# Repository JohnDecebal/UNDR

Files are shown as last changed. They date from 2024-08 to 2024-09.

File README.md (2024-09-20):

# UNDR AUTO: Automatic WDT Tool for Espresso

## Description

UNDR AUTO is a fully automatic WDT (Weiss Distribution Technique) tool designed for espresso enthusiasts. This open-source DIY project combines 3D printed parts with electronic and mechanical components to create a precise and customizable coffee distribution tool. By evenly distributing coffee grounds in the portafilter basket, UNDR AUTO aims to improve the consistency and quality of espresso shots.

## Key Features

- Fully automatic operation with proximity sensor activation
- Adjustable portafilter basket depth
- Variable speed control for vertical movement and distribution
- Customizable distribution patterns with 24 needle slots
- Wi-Fi control via onboard ESP32-S3 webserver
- Compact design with custom UNDR PCB

## Components Overview

The UNDR AUTO utilizes a mix of off-the-shelf and custom components:

- NEMA 17 Stepper Motors for precise movement
- Lead Screw System for vertical adjustment
- Custom 3D printed parts for the main structure
- UNDR PCB with ESP32-S3 for control and connectivity
- Various fasteners and electronic components

For a detailed list, please refer to the Bill of Materials (BOM) in this repository.

## Current Status and Limitations

**Important:** UNDR AUTO is currently in a prototype stage. Potential builders should be aware of the following:

1. Some 3D printed parts may require minor adjustments for proper fit.
2. The current wiring setup is not optimal and requires careful handling.
3. Assembly can be challenging, with some hard-to-reach fastening points.
4. The portafilter mount is specifically designed for Cafe Racer machines and will need modification for other models.
5. There's significant room for improvement in various aspects of the design.

We welcome contributions to address these limitations and enhance the overall design.

## Assembly Guide

Follow these detailed steps to assemble your UNDR AUTO:

1. **3D Printing:**
   - Print all parts listed in the "3D Printed Parts" section of the BOM.
   - Ensure prints are clean and free of defects. Sand parts if necessary for proper fit.
   - Pay special attention to the tolerances of connecting parts.

2. **Prepare the Main Body:**
   - Assemble the four parts of the main body, ensuring they fit snugly together.
   - Install M4 heated inserts into designated holes on the main body. Use a soldering iron to carefully melt the inserts into place.
   - Install 2 heated inserts on the lead screw mount.
   - Apply a strong adhesive to glue the grounds shield holder in place on the body. Ensure proper alignment before the glue sets.

3. **Motor and Lead Screw Installation:**
   - Attach the NEMA 17 stepper motor to the motor mount using M3 screws. Ensure the motor is securely fastened.
   - Install the lead screw system, carefully aligning it with the motor shaft. Use a coupling to connect the motor shaft to the lead screw.

4. **Carriage and Portafilter Mount Assembly:**
   - Install 4 bearings (ID 4mm x OD 8mm x Width 3mm) onto the carriage.
   - Attach the lead screw nut to the carriage using two M3 tapping screws.
   - Connect the portafilter mount to the leadscrew carriage. Note: This connection should be secure but allow for some movement to accommodate different portafilter sizes.

5. **Electronics Installation:**
   - Place the UNDR PCB in the designated space at the bottom of the tool. 
   - Note: The current design doesn't include mounting points for the PCB. Handle with care when moving the assembled unit.
   - Connect the ESP32-S3 to the PCB, ensuring all pins are properly aligned.
   - Install the proximity sensor.

6. **Wiring:**
   - Connect stepper motors to the PCB using the provided cables. Double-check the connections to ensure proper motor direction.
   - Carefully route all wires to avoid interference with moving parts.
   - Use cable ties or electrical tape to secure wires neatly along the frame of the device.

7. **Distributor Assembly:**
   - Assemble the distributor, magnetic connector, lid, arm, and cog.
   - Ensure the distributor spins freely and is properly aligned with the portafilter position.

8. **Lid Assembly:**
   - Assemble the lid using its 4 parts.
   - If desired, install small neodymium magnets in the provided slots for a satisfying close. Ensure polarity is correct for proper attraction to the main body.

9. **Tray Preparation:**
   - Glue magnets in place on the tray and corresponding spots on the body. This allows the tray to snap in place and be easily removed for cleaning.

10. **Final Assembly:**
    - Attach the assembled lid to the main body. Verify that it opens and closes smoothly.
    - Install the bottom lid, securing it with the appropriate screws.
    - Attach the threaded grounds shield to its glued holder, ensuring it's properly aligned with the distributor.

11. **Software Installation:**
    - Connect the ESP32 to your computer using a USB cable.
    - Download the latest firmware from the GitHub repository.
    - Use the Arduino IDE or your preferred ESP32 flashing tool to upload the code to the ESP32.
    - Verify that the upload was successful by checking for any error messages in the IDE.

12. **Testing and Calibration:**
    - Power on the device and connect to its Wi-Fi network (default SSID: "UNDR AUTO").
    - Access the web interface by navigating to 192.168.1.100 in your web browser.
    - Use the interface to test all movements: vertical travel, distribution rotation, and sensor activation.
    - Adjust settings as needed for your specific setup and preferences.

**Important Assembly Tips:**
- Use 90-degree allen wrenches for hard-to-reach fasteners, particularly in the main body assembly.
- Take your time and don't force parts together. If something doesn't fit, double-check the 3D print quality and sand if necessary.
- If using a portafilter other than Cafe Racer, you'll need to modify the mount design. Measure your portafilter carefully and adjust the 3D model accordingly.
- When gluing parts (like magnets or the grounds shield holder), ensure proper alignment before the glue sets.
- When flashing the code, make sure you have the correct board and port selected in your IDE.
- If you encounter any issues during the flashing process, double-check your connections and try resetting the ESP32.

Remember, this is a prototype design and you may encounter challenges during assembly. Don't hesitate to reach out to the community for support or share your improvement ideas!

## Usage Instructions

1. Connect to the UNDR AUTO Wi-Fi network
2. Access the web interface at 192.168.1.100
3. Configure settings (basket depth, speeds, rotation)
4. Place the filled portafilter on the mount
5. The device will automatically start the distribution process
6. Remove the portafilter and tamp as usual

Note: The current version does not support profile saving or live monitoring.

## Customization and Contribution

We strongly encourage users to customize the UNDR AUTO and contribute to its development. Here are some ways you can get involved:

### Customization

1. **Portafilter Mount:**
   - The current design is specific to Cafe Racer machines. We encourage users with different machines to create and share alternative designs.
   - When designing a new mount:
     - Carefully measure your portafilter's dimensions and unique features.
     - Use CAD software to modify the existing design or create a new one.
     - Consider factors like weight distribution and stability.
     - Share your designs with the community to help others with similar machines.

2. **Distribution Patterns:**
   - Experiment with different needle configurations in the 24 available slots.
   - Share your findings on how different patterns affect extraction.

3. **Software Tweaks:**
   - Modify the Arduino code to add new features or optimize existing ones.
   - If you create useful modifications, consider submitting them as pull requests.

### Contributing to the Project

We welcome contributions in various areas:

1. **Hardware Improvements:**
   - Refine the 3D printed parts for better fit and easier assembly.
   - Design solutions for improved wire management.
   - Develop a more secure method for attaching the portafilter mount to the leadscrew carriage.
   - Create a mounting solution for the PCB to prevent movement during operation.

2. **Software Enhancements:**
   - Implement profile saving and loading functionality in the web interface.
   - Add live monitoring capabilities for real-time adjustment during operation.
   - Develop over-the-air (OTA) firmware update functionality.
   - Create a mobile app for easier control and monitoring.

3. **Testing and Quality Assurance:**
   - Develop standardized testing procedures for assembled units.
   - Create a quality checklist for 3D printed parts.
   - Report bugs or suggest improvements based on your experience with the device.

### How to Contribute

1. Fork the repository on GitHub.
2. Create a new branch for your feature or bug fix.
3. Make your changes, ensuring they adhere to the project's coding standards.
4. Test your changes thoroughly.
5. Submit a pull request with a clear description of your changes and their benefits.
6. Engage in any feedback or discussion about your contribution.

### Community Guidelines

- Be respectful and constructive in all interactions.
- When reporting issues, provide as much detail as possible, including steps to reproduce.
- For major changes or new features, open an issue for discussion before submitting a pull request.
- Follow the project's coding style and documentation standards.
- Ensure all contributions are your own work or properly attributed.

Your contributions, no matter how small, are valuable to the project and the entire UNDR AUTO community. Together, we can create an exceptional tool for espresso enthusiasts worldwide!

## License

Copyright 2024 Ionut Decebal, UNDR COFFEE

This project is licensed under the CERN Open Hardware Licence Version 2 - Strongly Reciprocal (CERN-OHL-S v2). You may redistribute and modify this project under the terms specified at https://ohwr.org/cern_ohl_s_v2.txt.

This project is distributed WITHOUT ANY EXPRESS OR IMPLIED WARRANTY, INCLUDING OF MERCHANTABILITY, SATISFACTORY QUALITY AND FITNESS FOR A PARTICULAR PURPOSE. Please see the CERN-OHL-S v2 for applicable conditions.

## Acknowledgments and Contact

- Inspired by WDT techniques discussed on r/espresso
- Thanks to all contributors and testers

For questions or support, contact:
John Decebal - undr.coffee@gmail.com

Project Repository: [https://github.com/JohnDecebal/UNDR](https://github.com/JohnDecebal/UNDR)

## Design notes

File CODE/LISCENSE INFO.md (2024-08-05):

The STL files in this directory are part of the UNDR AUTO project.
Copyright 2024 Ionut Decebal, UNDR COFFEE
Licensed under CERN-OHL-S v2 (https://ohwr.org/cern_ohl_s_v2.txt)
Source: https://github.com/JohnDecebal/UNDR

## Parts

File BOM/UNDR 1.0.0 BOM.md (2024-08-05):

# Bill of Materials: 3D Printed Project

## Electronic and Mechanical Components

| Item No. | Description | Quantity | Notes | Link |
|---|---|---|---|---|
| 1 | NEMA 17 Stepper Motor | 2 | | |
| 2 | Connection Cables for Stepper Motors | 2 | | |
| 3 | UNDR PCB | 1 | | |
| 4 | ESP32-S3 | 1 | Microcontroller for Wi-Fi connectivity and control | |
| 5 | M4 Heated Inserts | 6 | | |
| 6 | M4 Screws | 6 | 2x 25mm, 4x 12mm | |
| 7 | M2 Screws | 9 | 4x 10mm, 4x 12mm, 1x 20mm | |
| 8 | M3 Tapping Screws | 2 | | |
| 9 | Bearings | 4 | ID 4mm x OD 8mm x Width 3mm | |
| 10 | Lead Screw System | 1 | 8mm T8 with 100mm leadscrew Type 3 | [Amazon Link](https://www.amazon.co.uk/iYueshare-100mm-Printer-Trapezoidal-Coupling/dp/B09K7HXKJD/) |
| 11 | Proximity Sensor | 1 | Heschen M4 Inductive Proximity Sensor (Sheld Type, 10-30VDC 150mA PNP, Normally Closed NC, 3 Wire) | |

## 3D Printed Parts

| Item No. | Description | Quantity | Notes | Link |
|---|---|---|---|---|
| 12 | Main Body | 1 | Made out of 4 parts | |
| 13 | Lid | 1 | Made out of 4 parts | |
| 14 | Portafilter Mount | 1 | | |
| 15 | Leadscrew Carriage | 1 | | |
| 16 | Threaded Grounds Shield | 1 | | |
| 17 | Threaded Grounds Shield Holder | 1 | | |
| 18 | Motor Mount | 1 | | |
| 19 | Bottom Lid | 1 | | |
| 20 | Tray | 1 | | |
| 21 | Distributor | 1 | | |
| 22 | Distributor Magnetic Connector | 1 | | |
| 23 | Distributor Lid | 1 | | |
| 24 | Distributor Arm | 1 | | |
| 25 | Distributor Cog | 1 | | |

## Notes:
- Consider adding any required tools or consumables (e.g., filament for 3D printing)
- Verify that all necessary connecting parts (e.g., nuts, washers) are included
- Ensure you have enough filament for all 3D printed parts
- Use the 'Link' column to add URLs for purchasing components or downloading 3D model files

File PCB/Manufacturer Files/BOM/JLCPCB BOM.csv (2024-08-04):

Comment | Designator | Footprint | LCSC Part Number
10nF | C1 | Capacitor_SMD:C_0603_1608Metric | C100042
2.2uF | C2, C3 | Capacitor_SMD:C_0805_2012Metric | C19110
220uF | C4 | Capacitor_Tantalum_SMD:CP_EIA-7343-31_Kemet-D | C8024
22uF | C5 | Capacitor_SMD:C_1206_3216Metric | C12891
10uF | C6 | Capacitor_SMD:C_1206_3216Metric | C13585
100nF | C7 | Capacitor_SMD:C_1206_3216Metric | C24497
100uF | C8, C9 | Capacitor_SMD:CP_Elec_8x10 | C336212
B340A | D1 | Diode_SMD:D_SMA | C64982
SMAJ12CA-TR | D2 | Diode_SMD:D_SMA | C132951
Yellow | D3 | LED_SMD:LED_0603_1608Metric | C72038
DC-005-20A | J1 | Connector_BarrelJack:BarrelJack_Wuerth_6941xx301002 | C136744
Conn_01x03 | J2 | TerminalBlock_Phoenix:TerminalBlock_Phoenix_PT-1,5-3-3.5-H_1x03_P3.50mm_Horizontal | C557655
Conn_01x04 | J3, J5 | Connector_JST:JST_XH_B4B-XH-AM_1x04_P2.50mm_Vertical | C161871
Conn_02x03_Odd_Even | J4, J6 | Connector_PinHeader_2.54mm:PinHeader_2x03_P2.54mm_Vertical | C706893
Conn_01x22 | J7, J8 | Plugin,P=2.54mm | C7499337
Conn_01x08 | J9, J10, J11, J12 | Plugin,P=2.54mm | C2935979
22uH | L1 | SMD | C9905
HSU60P03 | Q1 | Package_TO_SOT_SMD:TO-252-2 | C845611
13k | R1 | Resistor_SMD:R_0603_1608Metric | C217729
4.12k | R2 | Resistor_SMD:R_0603_1608Metric | C861436
10k | R3, R6 | Resistor_SMD:R_0603_1608Metric | C25804
56k | R4 | Resistor_SMD:R_0603_1608Metric | C23206
18k | R5 | Resistor_SMD:R_0603_1608Metric | C25810
330R | R7 | Resistor_SMD:R_0603_1608Metric | C23138
TPS5430DDA | U1 | Package_SO:TI_SO-PowerPAD-8_ThermalVias | C9864

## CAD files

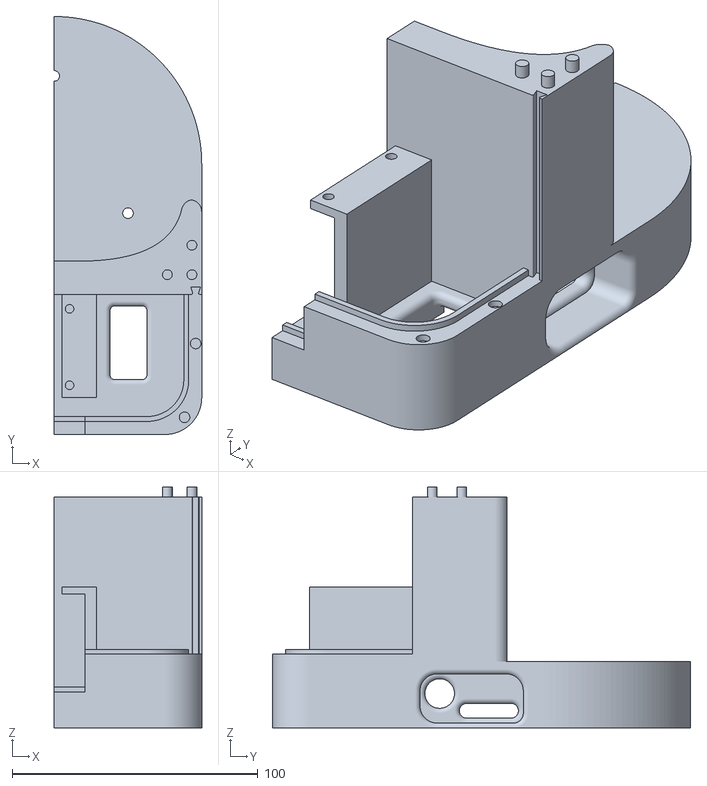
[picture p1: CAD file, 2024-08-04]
3D PRINTING/MAIN BODY/MAIN BODY - BODY LOWER LEFT.stl
60.0 x 170.0 x 98.0

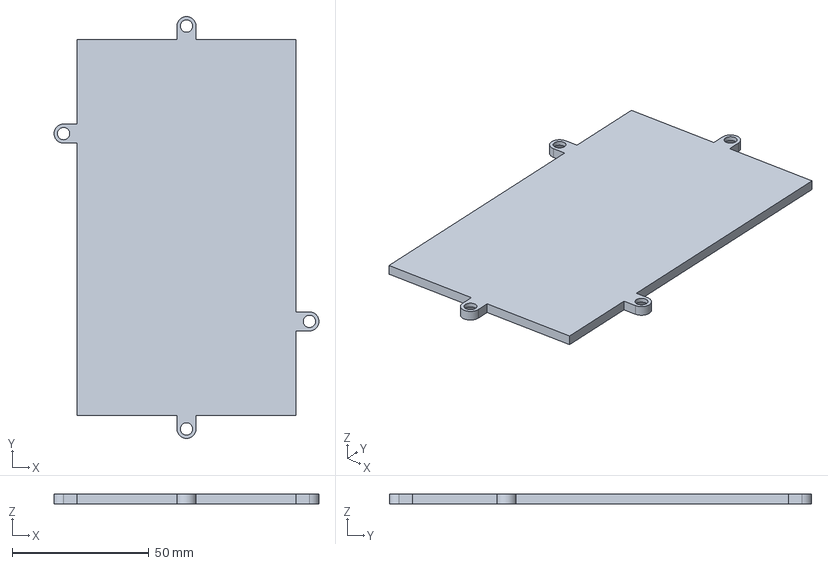
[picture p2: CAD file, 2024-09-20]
STEP/Assembly 1 - BOTTOM LID.step
97.0 x 154.5 x 3.50 mm

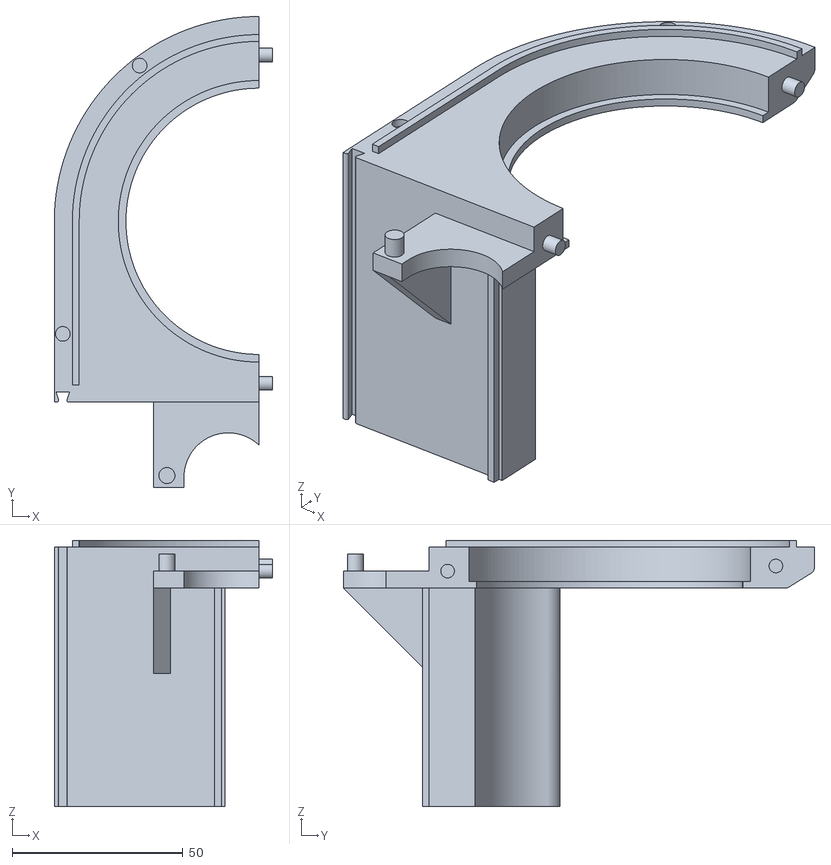
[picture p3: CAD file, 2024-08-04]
3D PRINTING/MAIN BODY/MAIN BODY - BODY UPPER RIGHT.stl
64.0 x 138.0 x 78.0

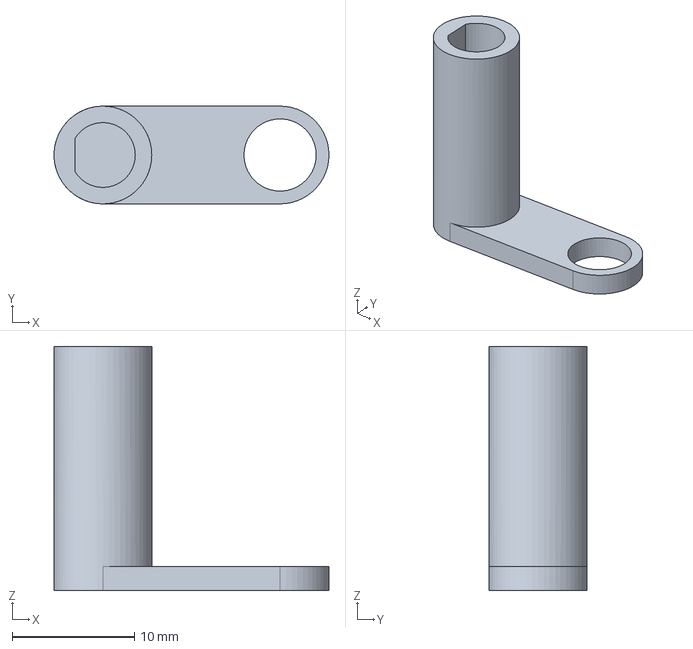
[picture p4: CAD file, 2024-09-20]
STEP/Assembly 1 - DISTRIBUTOR ARM.step
22.5 x 8.00 x 20.0 mm

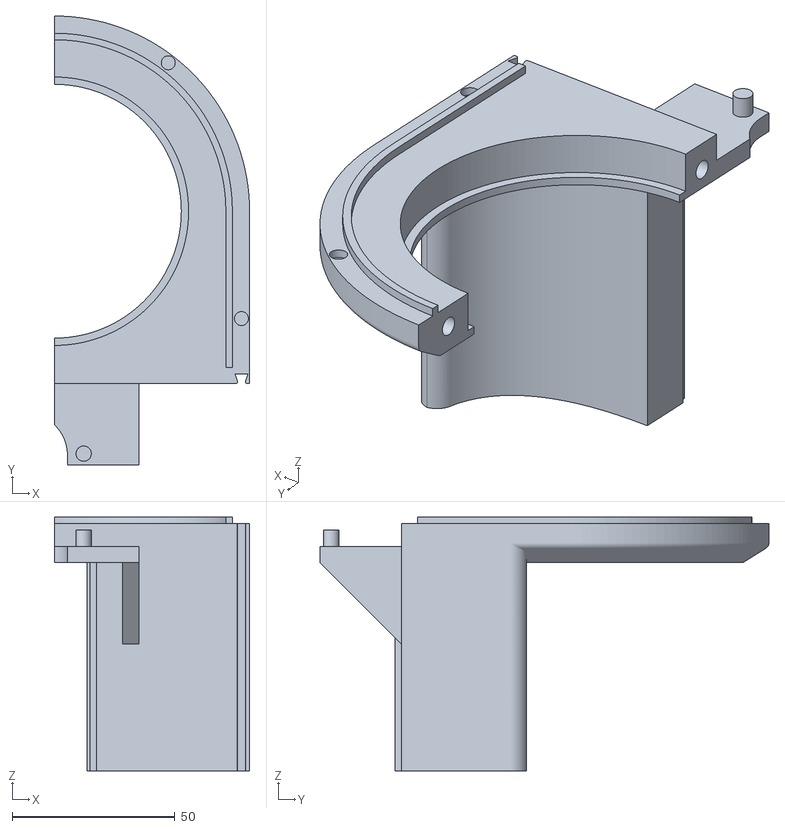
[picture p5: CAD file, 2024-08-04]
3D PRINTING/MAIN BODY/MAIN BODY - BODY UPPER LEFT.stl
60.0 x 138.0 x 78.0

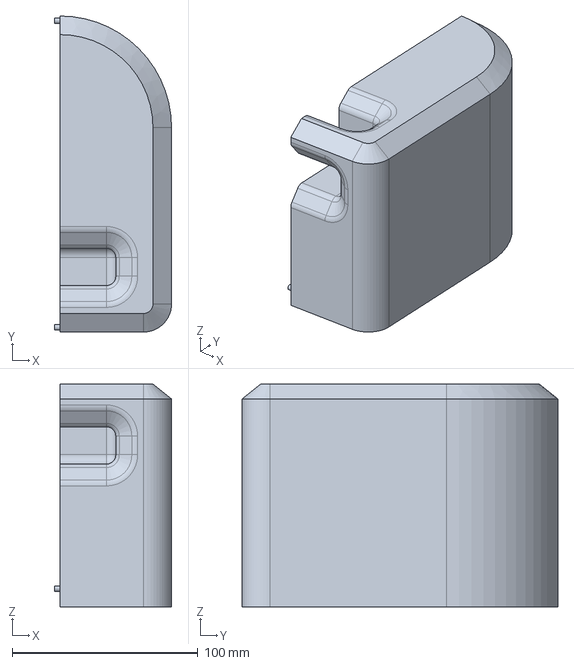
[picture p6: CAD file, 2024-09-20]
STEP/Assembly 1 - LID UP LEFT.step
63.0 x 170.0 x 119.8 mm

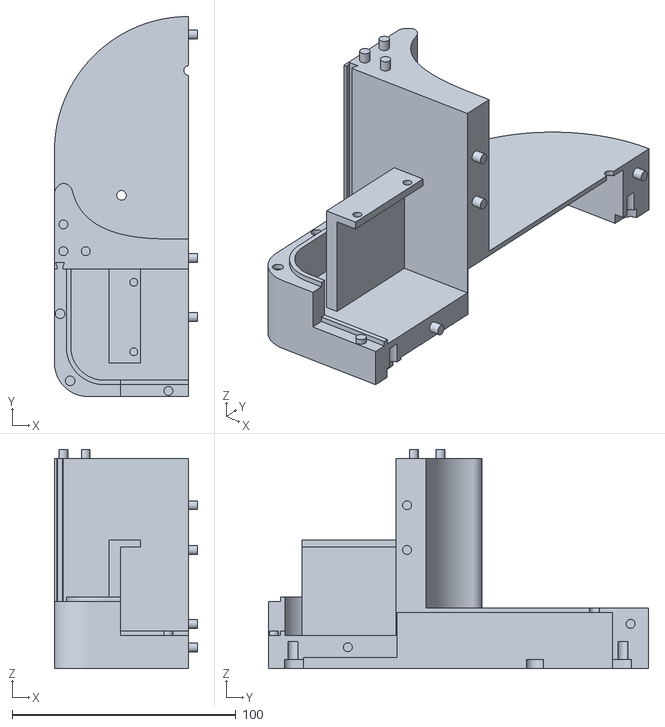
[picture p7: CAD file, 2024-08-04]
3D PRINTING/MAIN BODY/MAIN BODY - BODY LOWER RIGHT.stl
64.0 x 170.0 x 98.0

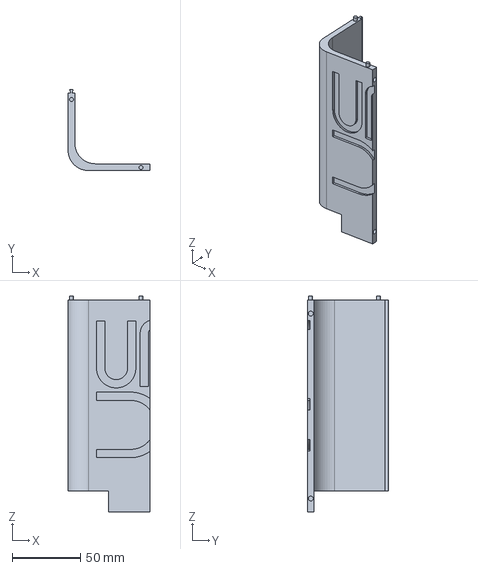
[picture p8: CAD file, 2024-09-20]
STEP/Assembly 1 - LID LOW RIGHT.step
60.0 x 59.4 x 158.0 mm

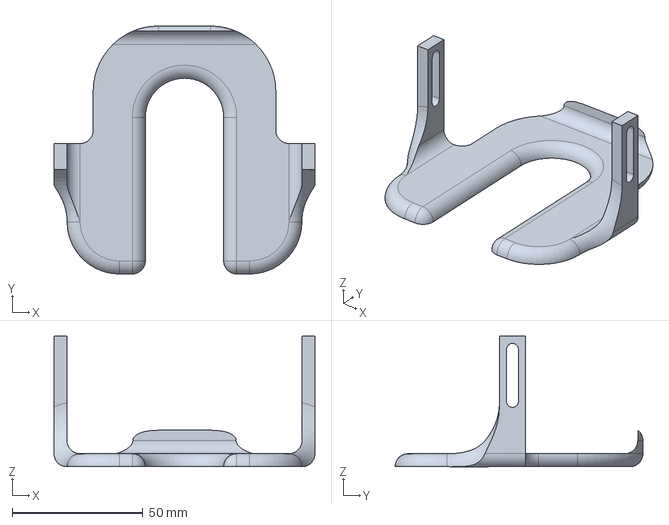
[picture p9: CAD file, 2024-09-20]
STEP/Assembly 1 - PORTAFILTER MOUNT BOTTOM.step
100.0 x 95.0 x 50.0 mm

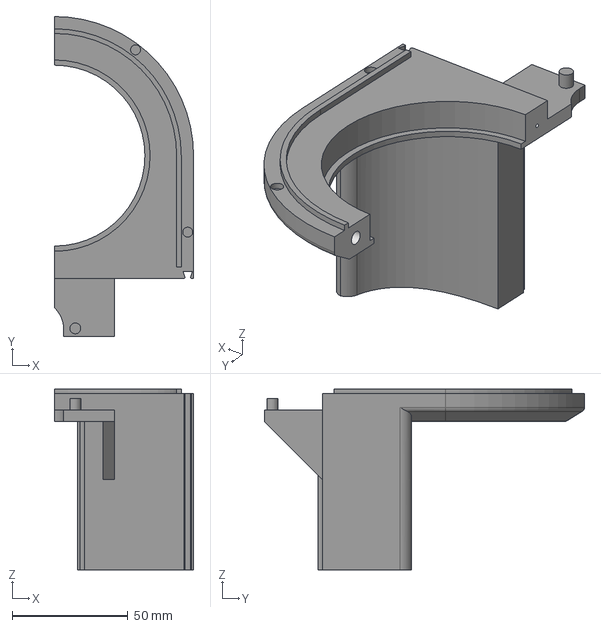
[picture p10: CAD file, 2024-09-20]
STEP/Assembly 1 - BODY UPPER LEFT.step
60.0 x 138.0 x 78.0 mm

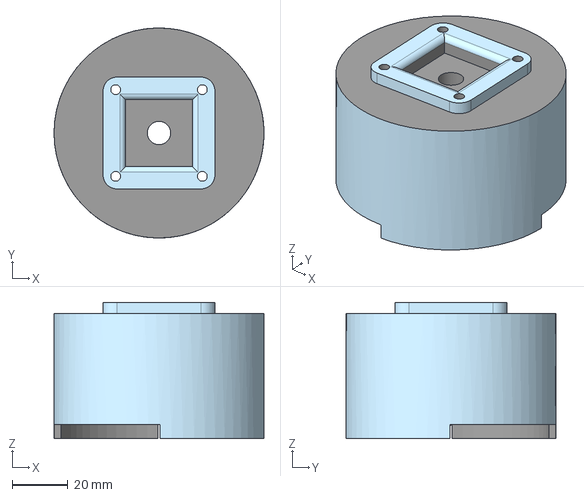
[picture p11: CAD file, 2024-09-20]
STEP/Assembly 1 - MOTOR MOUNT.step
75.1 x 75.1 x 48.7 mm

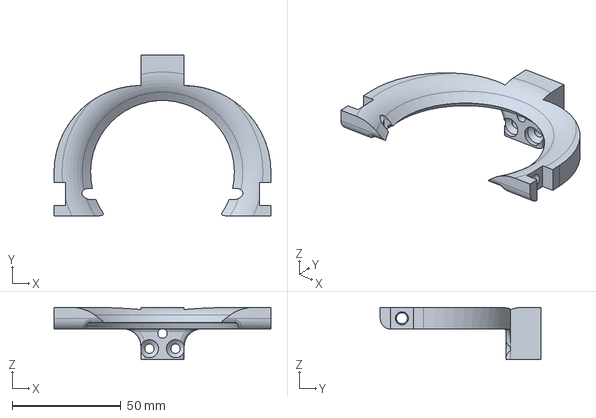
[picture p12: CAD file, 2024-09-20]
STEP/Assembly 1 - PORTAFILTER MOUNT TOP.step
100.0 x 74.0 x 24.0 mm

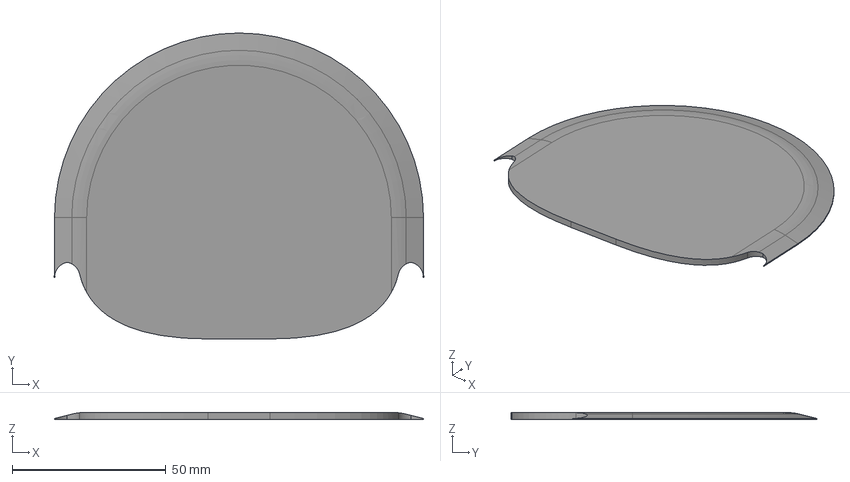
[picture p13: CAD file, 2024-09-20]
STEP/Assembly 1 - TRAY.step
120.0 x 99.5 x 2.40 mm

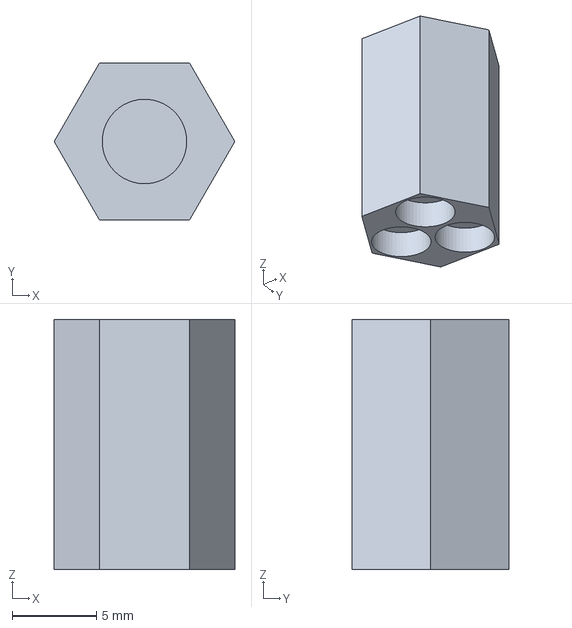
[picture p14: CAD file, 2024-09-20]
STEP/Assembly 1 - INNER DISTRIBUTOR MAG.step
10.7 x 9.27 x 14.8 mm

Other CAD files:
STEP/Assembly 1 - BODY UPPER RIGHT.step
STEP/Assembly 1 - INNER BARREL.step
STEP/Assembly 1 - OUTTER BARREL.step
STEP/Assembly 1 - DISTRIBUTOR COG.step
3D PRINTING/BOTTOM LID.stl
3D PRINTING/DRIVE SYSTEM/DISTRIBUTOR SYSTEM - DISTRIBUTOR COG.stl
3D PRINTING/DRIVE SYSTEM/DRIVE SYSTEM - DISTRIBUTOR MAGNET CONNECTOR.stl
3D PRINTING/DRIVE SYSTEM/DRIVE SYSTEM - DISTRIBUTOR ARM.stl
3D PRINTING/DRIVE SYSTEM/DRIVE SYSTEM - DISTRIBUTOR LID.stl
3D PRINTING/DRIVE SYSTEM/DRIVE SYSTEM - DISTRIBUTOR.stl
3D PRINTING/GROUND SHIELD.stl
3D PRINTING/GROUNDS SHIED HOLDER.stl
3D PRINTING/LEADSCREW CARRIAGE.stl
3D PRINTING/LID/LID - LID LOW LEFT.stl
3D PRINTING/LID/LID - LID LOW RIGHT.stl
3D PRINTING/LID/LID - LID UP LEFT.stl
3D PRINTING/LID/LID - LID UP RIGHT.stl
3D PRINTING/PORTAFILTER MOUNT.stl
3D PRINTING/TRAY.stl
STEP/Assembly 1 - BODY LOWER LEFT.step
STEP/Assembly 1 - BODY LOWER RIGHT.step
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

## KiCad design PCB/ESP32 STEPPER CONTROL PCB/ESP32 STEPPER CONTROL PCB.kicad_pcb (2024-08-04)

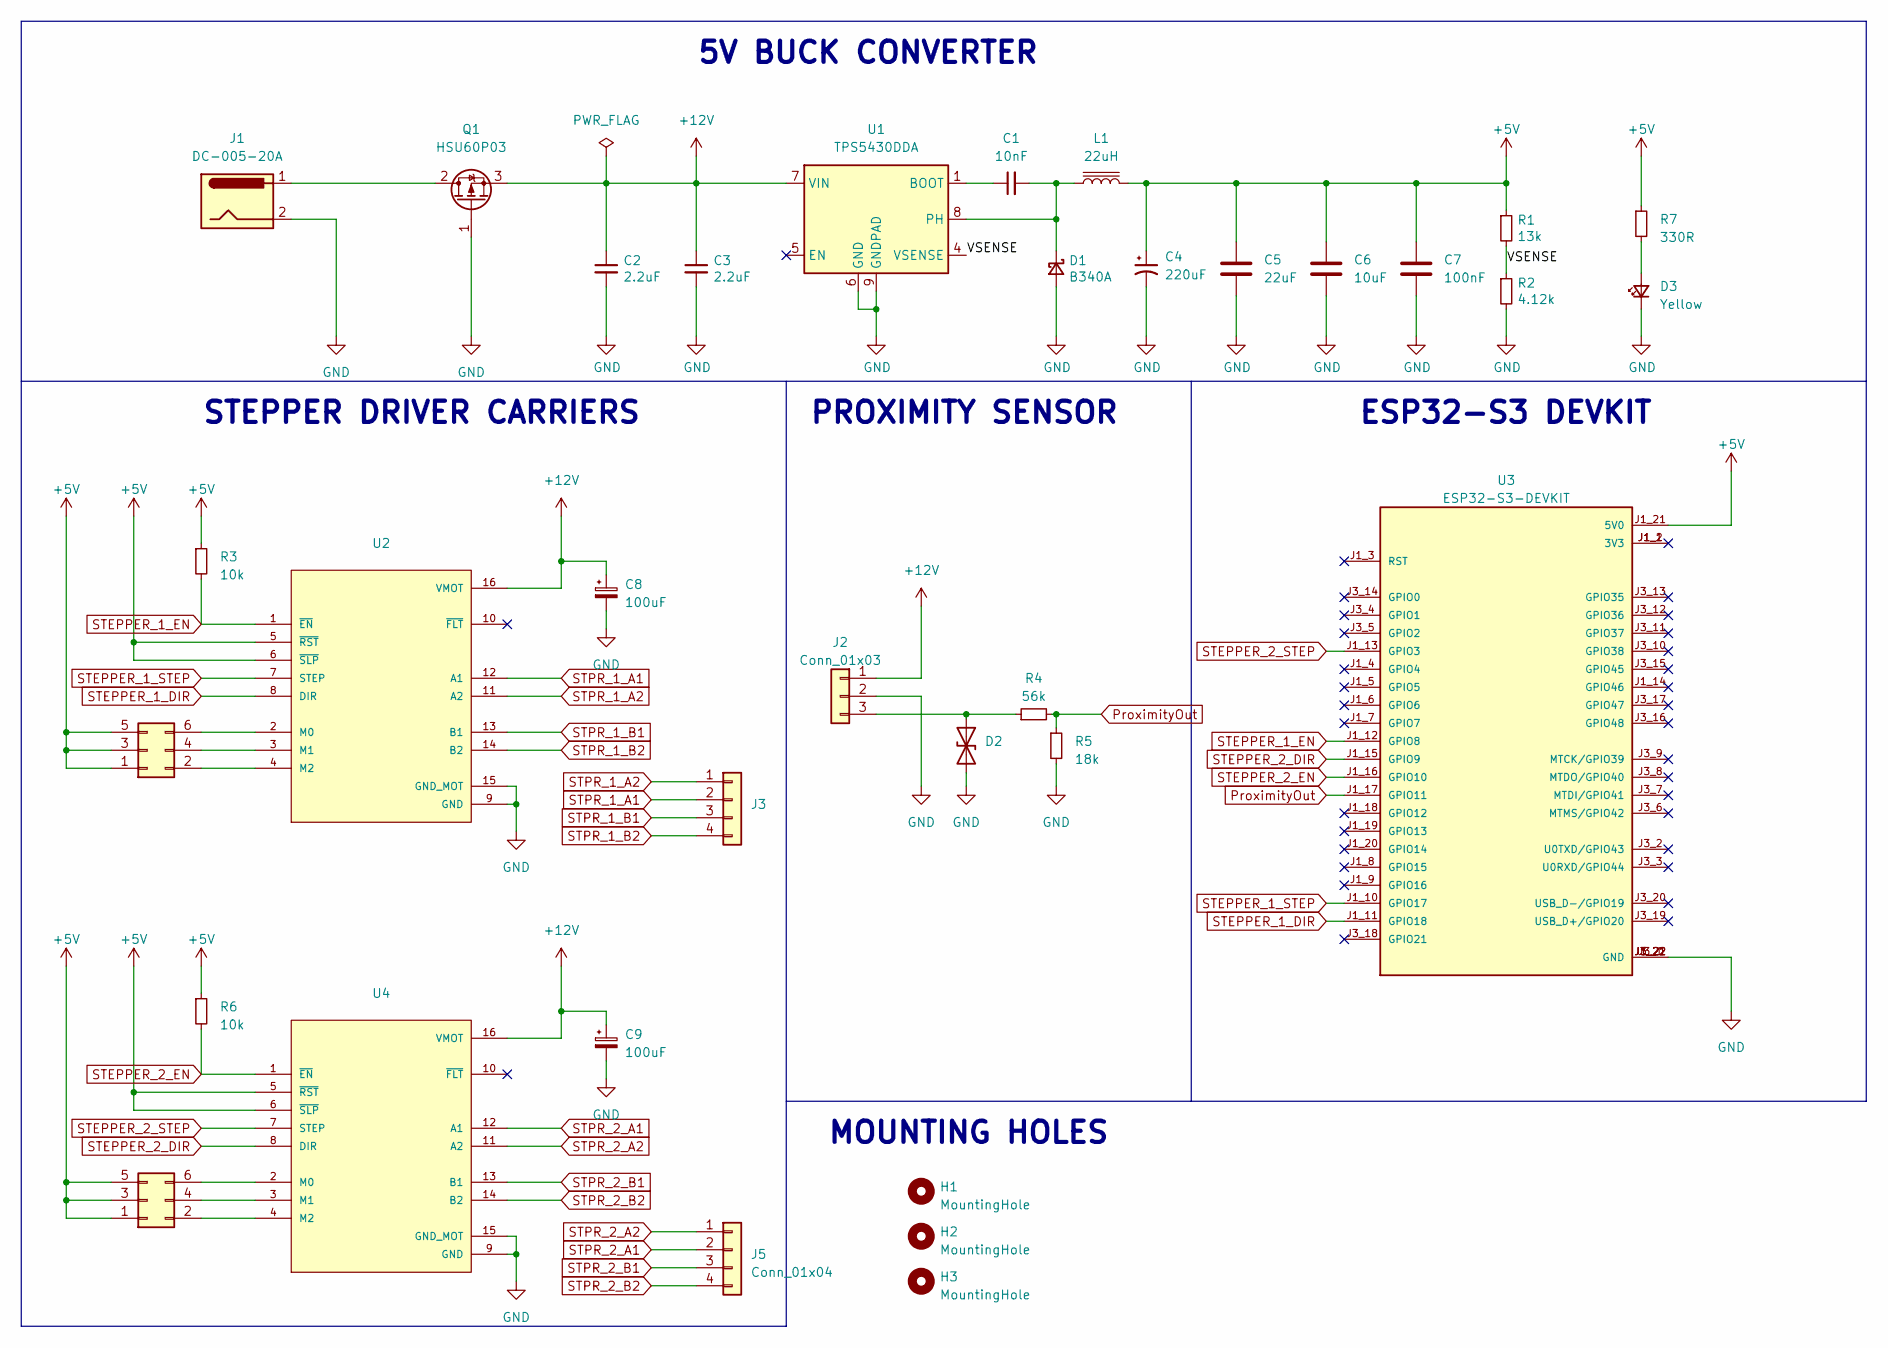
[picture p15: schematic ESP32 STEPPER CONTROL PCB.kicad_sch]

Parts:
C1: 10nF; C_0603_1608Metric; LCSC Part # C100042
C2, C3: 2.2uF; C_0805_2012Metric; LCSC Part # C19110
C4: 220uF; CP_EIA-7343-31_Kemet-D; LCSC Part # C8024
C5: 22uF; C_1206_3216Metric; LCSC Part # C12891
C6: 10uF; C_1206_3216Metric; LCSC Part # C13585
C7: 100nF; C_1206_3216Metric; LCSC Part # C24497
C8, C9: 100uF; CP_Elec_8x10; LCSC Part # C336212
D1: B340A; D_SMA; LCSC Part # C64982
D2: SMAJ12CA-TR; D_SMA; LCSC Part # C132951
D3: Yellow; LED_0603_1608Metric; LCSC Part # C72038
H1, H2, H3: MountingHole; MountingHole_3.2mm_M3_DIN965
J1: DC-005-20A; BarrelJack_Wuerth_6941xx301002; LCSC Part # C136744
J2: Conn_01x03; TerminalBlock_Phoenix_PT-1,5-3-3.5-H_1x03_P3.50mm_Horizontal; LCSC Part # C557655
J3, J5: Conn_01x04; JST_XH_B4B-XH-AM_1x04_P2.50mm_Vertical; LCSC Part # C161871
J4, J6: Conn_02x03_Odd_Even; PinHeader_2x03_P2.54mm_Vertical; LCSC Part # C706893
L1: 22uH; SMDRI127-220MT; LCSC Part # C9905
Q1: HSU60P03; TO-252-2; LCSC Part # C845611
R1: 13k; R_0603_1608Metric; LCSC Part # C217729
R2: 4.12k; R_0603_1608Metric; LCSC Part # C861436
R3, R6: 10k; R_0603_1608Metric; LCSC Part # C25804
R4: 56k; R_0603_1608Metric; LCSC Part # C23206
R5: 18k; R_0603_1608Metric; LCSC Part # C25810
R7: 330R; R_0603_1608Metric; LCSC Part # C23138
U1: TPS5430DDA; TI_SO-PowerPAD-8_ThermalVias; LCSC Part # C9864
U2, U4: DRV8825_STEPPER_MOTOR_DRIVER_CARRIER
U3: ESP32-S3-DEVKIT; ESP32-S3-DEVKITC

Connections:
+5V: C4.1, C5.1, C6.1, C7.1, J4.1, J4.3, J4.5, J6.1, J6.3, J6.5, L1.2, R1.1, R3.1, R6.1, R7.1, U2.5 (~RST), U2.6 (~SLP), U3.J1_21 (5V0), U4.5 (~RST), U4.6 (~SLP)
+12V: C2.1, C3.1, C8.1, C9.1, J2.1, Q1.3 (S), U1.7 (VIN), U2.16 (VMOT), U4.16 (VMOT)
/VSENSE: R1.2, R2.1, U1.4 (VSENSE)
GND: C2.2, C3.2, C4.2, C5.2, C6.2, C7.2, C8.2, C9.2, D1.2 (A), D2.2 (A2), D3.1 (K), J1.2, J2.2, Q1.1 (G), R2.2, R5.2, U1.6 (GND), U1.9 (GNDPAD), U2.9 (GND), U2.15 (GND_MOT), U3.J1_22 (GND), U3.J3_1 (GND), U3.J3_21 (GND), U3.J3_22 (GND), U4.9 (GND), U4.15 (GND_MOT)
unnamed: C1.2, D1.1 (K), L1.1, U1.8 (PH)
unnamed: D2.1 (A1), J2.3, R4.1
unnamed: D3.2 (A), R7.2
unnamed: J4.2, U2.4 (M2)
unnamed: J4.4, U2.3 (M1)
unnamed: J4.6, U2.2 (M0)
unnamed: J6.2, U4.4 (M2)
unnamed: J6.4, U4.3 (M1)
unnamed: J6.6, U4.2 (M0)
unnamed: J1.1, Q1.2 (D)
unnamed: C1.1, U1.1 (BOOT)
ProximityOut: R4.2, R5.1, U3.J1_17 (GPIO11)
STEPPER_1_DIR: U2.8 (DIR), U3.J1_11 (GPIO18)
STEPPER_1_EN: R3.2, U2.1 (~EN), U3.J1_12 (GPIO8)
STEPPER_1_STEP: U2.7 (STEP), U3.J1_10 (GPIO17)
STEPPER_2_DIR: U3.J1_15 (GPIO9), U4.8 (DIR)
STEPPER_2_EN: R6.2, U3.J1_16 (GPIO10), U4.1 (~EN)
STEPPER_2_STEP: U3.J1_13 (GPIO3), U4.7 (STEP)
STPR_1_A1: J3.2, U2.12 (A1)
STPR_1_A2: J3.1, U2.11 (A2)
STPR_1_B1: J3.3, U2.13 (B1)
STPR_1_B2: J3.4, U2.14 (B2)
STPR_2_A1: J5.2, U4.12 (A1)
STPR_2_A2: J5.1, U4.11 (A2)
STPR_2_B1: J5.3, U4.13 (B1)
STPR_2_B2: J5.4, U4.14 (B2)

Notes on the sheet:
STEPPER DRIVER CARRIERS
PROXIMITY SENSOR
ESP32-S3 DEVKIT
5V BUCK CONVERTER
MOUNTING HOLES

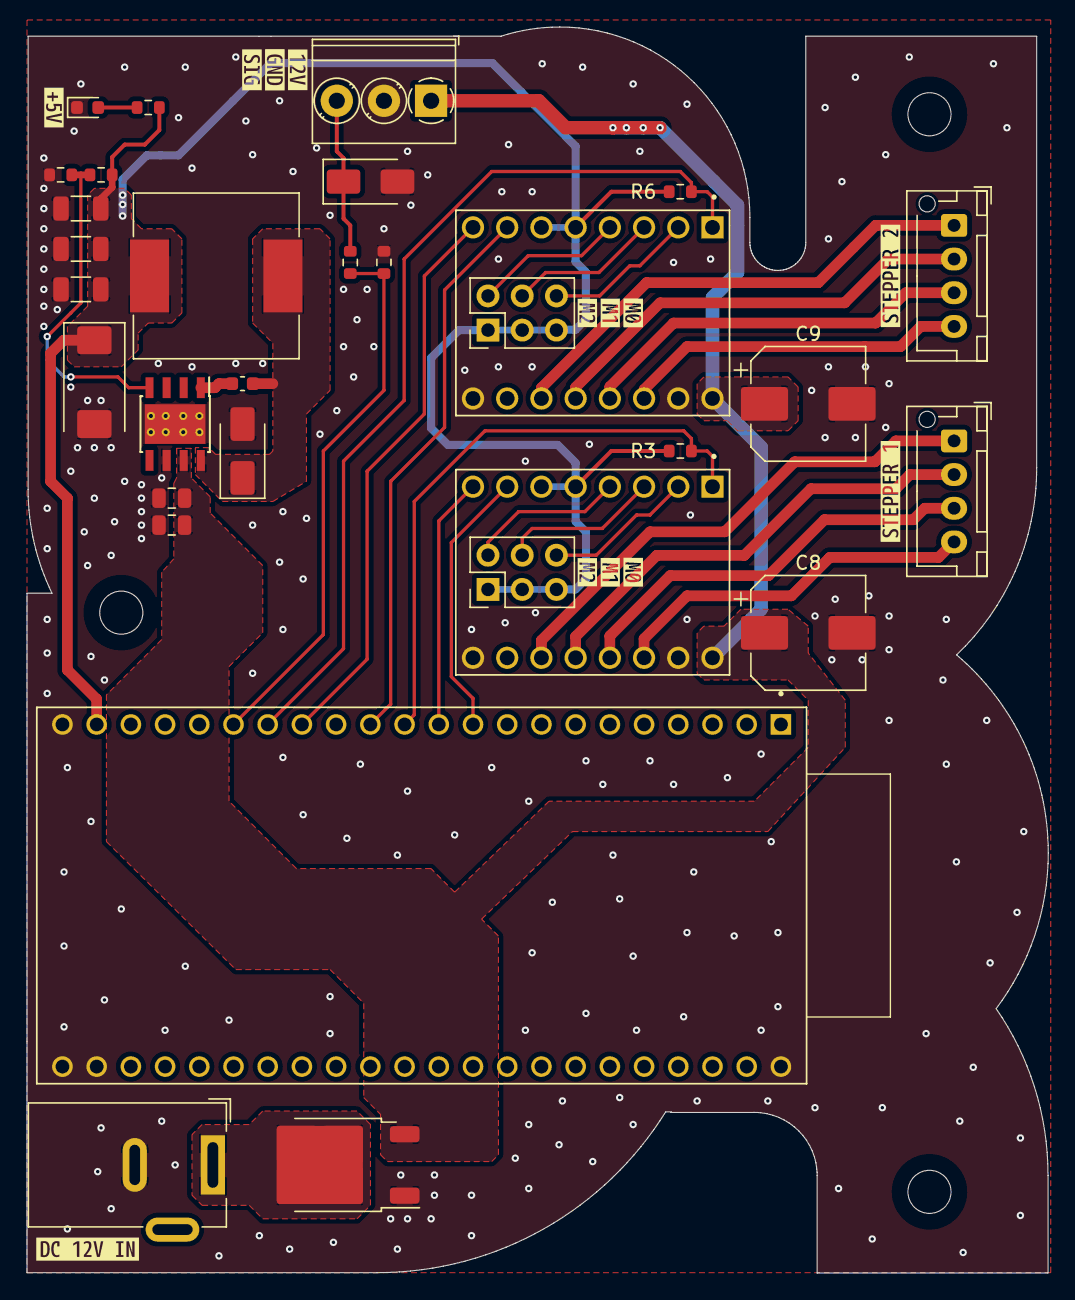
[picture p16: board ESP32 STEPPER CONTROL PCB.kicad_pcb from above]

Board: 2 copper layers, 75.8 x 92.5 mm, 47 parts (0 on the bottom side), 30 nets.

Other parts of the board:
kibuzzard-661D4DC0: G***; kibuzzard-661D4DC0
kibuzzard-661D7A6E: G***; kibuzzard-661D7A6E
kibuzzard-661D7A47: G***; kibuzzard-661D7A47
kibuzzard-661D7A91, kibuzzard-661D7A91#2: G***; kibuzzard-661D7A91
kibuzzard-661D7AAA, kibuzzard-661D7AAA#2: G***; kibuzzard-661D7AAA
kibuzzard-661D7AB9, kibuzzard-661D7AB9#2: G***; kibuzzard-661D7AB9
kibuzzard-661D7B73: G***; kibuzzard-661D7B73
kibuzzard-661D7B98: G***; kibuzzard-661D7B98
kibuzzard-661D7BA7: G***; kibuzzard-661D7BA7
kibuzzard-661D68F2: G***; kibuzzard-661D68F2

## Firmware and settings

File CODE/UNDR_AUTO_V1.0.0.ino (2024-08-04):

#include <WiFi.h>
#include <WebServer.h>
#include <AccelStepper.h>
#include <EEPROM.h>

const char* ssid = "UNDR AUTO";
const char* password = "undrauto";

WebServer server(80);

// Pin assignments
const int STEPPER1_PUL_PIN = 17;
const int STEPPER1_DIR_PIN = 18;
const int STEPPER2_PUL_PIN = 3;
const int STEPPER2_DIR_PIN = 9;
const int ENABLE_PIN_1 = 8;
const int ENABLE_PIN_2 = 10;
const int BUTTON_PIN = 11;

AccelStepper stepper1(1, STEPPER1_PUL_PIN, STEPPER1_DIR_PIN);
AccelStepper stepper2(1, STEPPER2_PUL_PIN, STEPPER2_DIR_PIN);

// Variables
int lastButtonState = 0;
int maxSpeed1; // Variable to store the maximum speed for stepper1
int maxSpeed2; // Variable to store the maximum speed for stepper2

// EEPROM addresses
const int ADDR_RPM = 0;
const int ADDR_REVS = 2;
const int ADDR_BASKET_DEPTH = 4;
const int ADDR_SPEED = 6;
const int ADDR_DIRECTION = 8;

// History
const int MAX_HISTORY = 25;

struct HistoryItem {
  unsigned long id;
  int rpm;
  int revs;
  int depth;
  int speed;
  int direction;
};

HistoryItem history[MAX_HISTORY];
int historyCount = 0;

// EEPROM functions
void EEPROMWriteInt(int address, int value) {
  byte low = value & 0xFF;
  byte high = (value >> 8) & 0xFF;
  EEPROM.write(address, low);
  EEPROM.write(address + 1, high);
  EEPROM.commit();
}

int EEPROMReadInt(int address) {
  byte low = EEPROM.read(address);
  byte high = EEPROM.read(address + 1);
  return (high << 8) | low;
}

// Motor control functions
void liftPortafilter(int basketDepthValue, int speedValue) {
  maxSpeed1 = speedValue * (800 / 60); // Assuming 800 steps per revolution
  stepper1.setCurrentPosition(0);
  stepper1.setMaxSpeed(maxSpeed1);
  stepper1.setAcceleration(800 * (speedValue / 60));
  stepper1.runToNewPosition(40*basketDepthValue);
}

void spinDistributor(int rpmValue, int revsValue, int directionValue) {
  maxSpeed2 = rpmValue * (3200 / 60); // Assuming 3200 steps per revolution
  stepper2.setCurrentPosition(0);
  stepper2.setMaxSpeed(maxSpeed2);
  stepper2.setAcceleration(3200 * (rpmValue / 60));
  int targetPosition = directionValue == 0 ? 3200 * revsValue : -3200 * revsValue;
  stepper2.runToNewPosition(targetPosition);
}

void lowerPortafilter() {
  stepper1.runToNewPosition(0);
}

String css() {
  String styles = "<style>";
  styles += "body { background-color: #000; color: #fff; font-family: 'Inter', sans-serif; margin: 0; padding: 0; min-height: 100vh; display: flex; flex-direction: column; }";
  styles += ".container { max-width: 800px; margin: 0 auto; padding: 20px; flex-grow: 1; display: flex; flex-direction: column; justify-content: center; }";
  styles += "h1 { text-align: center; margin-top: 0; }";
  styles += "form { margin-top: 30px; }";
  styles += "label { display: block; margin-bottom: 10px; }";
  styles += "input[type='number'], select { width: 100%; padding: 8px; background-color: #fff; color: #000; border: none; border-radius: 4px; box-sizing: border-box; }";
  styles += "input[type='submit'], input[type='button'] { display: block; width: 100%; padding: 10px; margin-top: 20px; background-color: #fff; color: #000; border: none; border-radius: 4px; cursor: pointer; }";
  styles += "table { width: 100%; border-collapse: collapse; }";
  styles += "th, td { padding: 8px; text-align: left; border-bottom: 1px solid #fff; }";
  styles += "@media screen and (max-width: 600px) {";
  styles += "input[type='number'], select { padding: 12px; }";
  styles += "input[type='submit'], input[type='button'] { padding: 12px; }";
  styles += "}";
  styles += "</style>";
  return styles;
}

void handleRoot() {
  String html = "<!DOCTYPE html><html><head>";
  html += "<title>UNDR AUTO</title>";
  html += "<meta name='viewport' content='width=device-width, initial-scale=1'>";
  html += "<link href='https://fonts.googleapis.com/css2?family=Inter:wght@400;700&display=swap' rel='stylesheet'>";
  html += css();
  html += "</head><body>";
  html += "<div class='container'>";
  html += "<h1>UNDR AUTO</h1>";
  html += "<form method='POST' action='/update'>";
  html += "<label for='rpm'>RPM:</label>";
  html += "<input type='number' id='rpm' name='rpm' value='" + String(EEPROMReadInt(ADDR_RPM)) + "' required>";
  html += "<label for='revs'>Revolutions:</label>";
  html += "<input type='number' id='revs' name='revs' value='" + String(EEPROMReadInt(ADDR_REVS)) + "' required>";
  html += "<label for='depth'>Basket Depth:</label>";
  html += "<input type='number' id='depth' name='depth' value='" + String(EEPROMReadInt(ADDR_BASKET_DEPTH)) + "' required>";
  html += "<label for='speed'>Speed:</label>";
  html += "<input type='number' id='speed' name='speed' value='" + String(EEPROMReadInt(ADDR_SPEED)) + "' required>";
  html += "<label for='direction'>Rotation Direction:</label>";
  html += "<select id='direction' name='direction'>";
  html += "<option value='0'";
  html += (EEPROMReadInt(ADDR_DIRECTION) == 0 ? " selected" : "");
  html += ">Clockwise</option>";
  html += "<option value='1'";
  html += (EEPROMReadInt(ADDR_DIRECTION) == 1 ? " selected" : "");
  html += ">Counterclockwise</option>";
  html += "</select>";
  html += "<input type='submit' value='Update'>";
  html += "</form>";
  html += "<form method='POST' action='/start'>";
  html += "<input type='submit' value='Start Distribution'>";
  html += "</form>";
  html += "<form method='GET' action='/manual'>";
  html += "<input type='submit' value='Manual Settings'>";
  html += "</form>";
  html += "<form method='GET' action='/history'>";
  html += "<input type='submit' value='View History'>";
  html += "</form>";
  html += "<form method='GET' action='/simulation'>";
  html += "<input type='submit' value='Simulation'>";
  html += "</form>";
  html += "</div>";
  html += "</body></html>";
  server.send(200, "text/html", html);
}

void handleUpdate() {
  if (server.hasArg("rpm")) {
    int rpmValue = server.arg("rpm").toInt();
    EEPROMWriteInt(ADDR_RPM, rpmValue);
  }
  if (server.hasArg("revs")) {
    int revsValue = server.arg("revs").toInt();
    EEPROMWriteInt(ADDR_REVS, revsValue);
  }
  if (server.hasArg("depth")) {
    int depthValue = server.arg("depth").toInt();
    EEPROMWriteInt(ADDR_BASKET_DEPTH, depthValue);
  }
  if (server.hasArg("speed")) {
    int speedValue = server.arg("speed").toInt();
    EEPROMWriteInt(ADDR_SPEED, speedValue);
  }
  if (server.hasArg("direction")) {
    int directionValue = server.arg("direction").toInt();
    EEPROMWriteInt(ADDR_DIRECTION, directionValue);
  }
  server.sendHeader("Location", "/");
  server.send(302);
}

void handleStart() {
  int rpmValue = EEPROMReadInt(ADDR_RPM);
  int revsValue = EEPROMReadInt(ADDR_REVS);
  int basketDepthValue = EEPROMReadInt(ADDR_BASKET_DEPTH);
  int speedValue = EEPROMReadInt(ADDR_SPEED);
  int directionValue = EEPROMReadInt(ADDR_DIRECTION);

  // Activate motors
  digitalWrite(ENABLE_PIN_1, LOW);
  digitalWrite(ENABLE_PIN_2, LOW);

  // Wait 0.5 seconds
  delay(500);

  // Lift portafilter
  liftPortafilter(basketDepthValue, speedValue);

  // Spin distributor
  spinDistributor(rpmValue, revsValue, directionValue);

  // Lower portafilter
  lowerPortafilter();

  // Deactivate motors
  digitalWrite(ENABLE_PIN_1, HIGH);
  digitalWrite(ENABLE_PIN_2, HIGH);

  // Add a new history item
  addHistoryItem(rpmValue, revsValue, basketDepthValue, speedValue, directionValue);

  server.sendHeader("Location", "/");
  server.send(302);
}

void handleManual() {
  String html = "<!DOCTYPE html><html><head>";
  html += "<title>UNDR AUTO - Manual Settings</title>";
  html += "<meta name='viewport' content='width=device-width, initial-scale=1'>";
  html += "<link href='https://fonts.googleapis.com/css2?family=Inter:wght@400;700&display=swap' rel='stylesheet'>";
  html += css();
  html += "</head><body>";
  html += "<div class='container'>";
  html += "<h1>Manual Settings</h1>";
  html += "<form method='POST' action='/stepper1'>";
  html += "<input type='submit' name='direction' value='Up'>";
  html += "<input type='submit' name='direction' value='Down'>";
  html += "</form>";
  html += "<form method='POST' action='/stepper2'>";
  html += "<input type='submit' name='direction' value='Clockwise'>";
  html += "<input type='submit' name='direction' value='Counter Clockwise'>";
  html += "</form>";
  html += "<form method='GET' action='/'>";
  html += "<input type='submit' value='Back'>";
  html += "</form>";
  html += "</div>";
  html += "</body></html>";
  server.send(200, "text/html", html);
}

void handleStepper1() {
  if (server.hasArg("direction")) {
    String direction = server.arg("direction");
    
    // Activate motor 1
    digitalWrite(ENABLE_PIN_1, LOW);
    
    if (direction == "Up") {
      int speedValue = EEPROMReadInt(ADDR_SPEED);
      maxSpeed1 = speedValue * (800 / 60);
      stepper1.setCurrentPosition(0);
      stepper1.setMaxSpeed(maxSpeed1);
      stepper1.setAcceleration(800 * (speedValue / 60));
      stepper1.runToNewPosition(100); // Move stepper 1 up by 100 steps
    } else if (direction == "Down") {
      int speedValue = EEPROMReadInt(ADDR_SPEED);
      maxSpeed1 = speedValue * (800 / 60);
      stepper1.setCurrentPosition(0);
      stepper1.setMaxSpeed(maxSpeed1);
      stepper1.setAcceleration(800 * (speedValue / 60));
      stepper1.runToNewPosition(-100); // Move stepper 1 down by 100 steps
    }
    
    // Deactivate motor 1
    digitalWrite(ENABLE_PIN_1, HIGH);
  }
  server.sendHeader("Location", "/manual");
  server.send(302);
}

void handleStepper2() {
  if (server.hasArg("direction")) {
    String direction = server.arg("direction");
    
    // Activate motor 2
    digitalWrite(ENABLE_PIN_2, LOW);
    
    if (direction == "Clockwise") {
      stepper2.setCurrentPosition(0);
      stepper2.setAcceleration(3200);
      stepper2.runToNewPosition(100); // Spin stepper 2 clockwise by 100 steps
    } else if (direction == "Counter Clockwise") {
      stepper2.setCurrentPosition(0);
      stepper2.setAcceleration(3200);
      stepper2.runToNewPosition(-100); // Spin stepper 2 counter clockwise by 100 steps
    }
    
    // Deactivate motor 2
    digitalWrite(ENABLE_PIN_2, HIGH);
  }
  server.sendHeader("Location", "/manual");
  server.send(302);
}

void handleSimulation() {
  String html = "<!DOCTYPE html><html><head>";
  html += "<title>UNDR AUTO - Simulation</title>";
  html += "<meta name='viewport' content='width=device-width, initial-scale=1'>";
  html += "<link href='https://fonts.googleapis.com/css2?family=Inter:wght@400;700&display=swap' rel='stylesheet'>";
  html += css();
  html += "</head><body>";
  html += "<div class='container'>";
  html += "<h1>Simulation</h1>";
  html += "<canvas id='simulationCanvas' width='600' height='600'></canvas>";
  html += "<div>";
  for (int i = 0; i < 6; i++) {
    html += "<label><input type='checkbox' id='slot" + String(i) + "' checked> Slot " + String(i + 1) + "</label><br>";
  }
  html += "</div>";
  html += "<form method='GET' action='/'>";
  html += "<input type='submit' value='Back'>";
  html += "</form>";
  html += "</div>";
  html += "<script>";
  html += "const canvas = document.getElementById('simulationCanvas');";
  html += "const ctx = canvas.getContext('2d');";
  html += "const centerX = canvas.width / 2;";
  html += "const centerY = canvas.height / 2;";
  html += "const outerRadius = 250;";
  html += "const innerRadius = 129;";
  html += "const slotRadius = 17.2;";
  html += "const slotPositions = [";
  html += "  { x: 0, y: -innerRadius + slotRadius },";
  html += "  { x: (innerRadius - slotRadius) * Math.cos(Math.PI / 3), y: -(innerRadius - slotRadius) * Math.sin(Math.PI / 3) },";
  html += "  { x: (innerRadius - slotRadius) * Math.cos(Math.PI / 3), y: (innerRadius - slotRadius) * Math.sin(Math.PI / 3) },";
  html += "  { x: 0, y: innerRadius - slotRadius },";
  html += "  { x: -(innerRadius - slotRadius) * Math.cos(Math.PI / 3), y: (innerRadius - slotRadius) * Math.sin(Math.PI / 3) },";
  html += "  { x: -(innerRadius - slotRadius) * Math.cos(Math.PI / 3), y: -(innerRadius - slotRadius) * Math.sin(Math.PI / 3) },";
  html += "];";
  html += "let angle = 0;";
  html += "function drawSimulation() {";
  html += "  ctx.clearRect(0, 0, canvas.width, canvas.height);";
  html += "  ctx.beginPath();";
  html += "  ctx.arc(centerX, centerY, outerRadius, 0, Math.PI * 2);";
  html += "  ctx.strokeStyle = '#ffffff';";
  html += "  ctx.lineWidth = 2;";
  html += "  ctx.stroke();";
  html += "  ctx.beginPath();";
  html += "  ctx.arc(centerX + outerRadius - innerRadius + innerRadius * Math.cos(angle), centerY + innerRadius * Math.sin(angle), innerRadius, 0, Math.PI * 2);";
  html += "  ctx.strokeStyle = '#ffffff';";
  html += "  ctx.lineWidth = 2;";
  html += "  ctx.stroke();";
  html += "  for (let i = 0; i < slotPositions.length; i++) {";
  html += "    if (document.getElementById('slot' + i).checked) {";
  html += "      const slot = slotPositions[i];";
  html += "      const rotatedSlot = rotatePoint(slot, angle);";
  html += "      ctx.beginPath();";
  html += "      ctx.arc(centerX + outerRadius - innerRadius + rotatedSlot.x, centerY + rotatedSlot.y, slotRadius, 0, Math.PI * 2);";
  html += "      ctx.fillStyle = '#ffffff';";
  html += "      ctx.fill();";
  html += "    }";
  html += "  }";
  html += "  angle += 0.02;";
  html += "  requestAnimationFrame(drawSimulation);";
  html += "}";
  html += "function rotatePoint(point, angle) {";
  html += "  const rotatedX = point.x * Math.cos(angle) - point.y * Math.sin(angle);";
  html += "  const rotatedY = point.x * Math.sin(angle) + point.y * Math.cos(angle);";
  html += "  return { x: rotatedX, y: rotatedY };";
  html += "}";
  html += "drawSimulation();";
  html += "</script>";
  html += "</body></html>";
  server.send(200, "text/html", html);
}

void saveHistory() {
  EEPROM.write(512, historyCount);
  for (int i = 0; i < historyCount; i++) {
    EEPROM.put(514 + i * sizeof(HistoryItem), history[i]);
  }
  EEPROM.commit();
}

void loadHistory() {
  historyCount = EEPROM.read(512);
  if (historyCount > MAX_HISTORY) {
    historyCount = MAX_HISTORY;
  }
  for (int i = 0; i < historyCount; i++) {
    EEPROM.get(514 + i * sizeof(HistoryItem), history[i]);
  }
}

void addHistoryItem(int rpm, int revs, int depth, int speed, int direction) {
  if (historyCount >= MAX_HISTORY) {
    for (int i = 1; i < MAX_HISTORY; i++) {
      history[i - 1] = history[i];
    }
    historyCount--;
  }

  HistoryItem newItem = {
    millis(),
    rpm,
    revs,
    depth,
    speed,
    direction
  };
  history[historyCount] = newItem;
  historyCount++;

  saveHistory();
}

void handleHistory() {
  String html = "<!DOCTYPE html><html><head>";
  html += "<title>UNDR AUTO - History</title>";
  html += "<meta name='viewport' content='width=device-width, initial-scale=1'>";
  html += "<link href='https://fonts.googleapis.com/css2?family=Inter:wght@400;700&display=swap' rel='stylesheet'>";
  html += css();
  html += "</head><body>";
  html += "<div class='container'>";
  html += "<h1>History</h1>";
  html += "<table>";
  html += "<thead><tr><th>Timestamp</th><th>RPM</th><th>Revolutions</th><th>Depth</th><th>Speed</th><th>Direction</th></tr></thead>";
  html += "<tbody>";

  for (int i = 0; i < historyCount; i++) {
    html += "<tr>";
    html += "<td>" + String(history[i].id) + "</td>";
    html += "<td>" + String(history[i].rpm) + "</td>";
    html += "<td>" + String(history[i].revs) + "</td>";
    html += "<td>" + String(history[i].depth) + "</td>";
    html += "<td>" + String(history[i].speed) + "</td>";
    html += "<td>" + String(history[i].direction == 0 ? "Clockwise" : "Counterclockwise") + "</td>";
    html += "</tr>";
  }

  html += "</tbody></table>";
  html += "<form method='GET' action='/'>";
  html += "<input type='submit' value='Back'>";
  html += "</form>";
  html += "</div>";
  html += "</body></html>";

  server.send(200, "text/html", html);
}

void setup() {
  // Initialize EEPROM
  EEPROM.begin(512);

  // Initialize Serial communication
  Serial.begin(115200);

  // Create Wi-Fi access point
  WiFi.softAP(ssid, password);

  // Assign a static IP address to the ESP32-S3
  IPAddress local_IP(192, 168, 1, 100);
  IPAddress gateway(192, 168, 1, 1);
  IPAddress subnet(255, 255, 255, 0);
  WiFi.softAPConfig(local_IP, gateway, subnet);

  // Print the IP address of the ESP32-S3
  Serial.print("Access Point IP address: ");
  Serial.println(local_IP);

  // Set up the web server routes
  server.on("/", handleRoot);
  server.on("/update", handleUpdate);
  server.on("/start", handleStart);
  server.on("/manual", handleManual);
  server.on("/stepper1", handleStepper1);
  server.on("/stepper2", handleStepper2);
  server.on("/history", handleHistory);
  server.on("/simulation", handleSimulation);

  // Start the web server
  server.begin();

  stepper1.setMaxSpeed(12000); // Initial value, will be updated based on speed
  stepper2.setMaxSpeed(12000); // Initial value, will be updated based on RPM

  pinMode(BUTTON_PIN, INPUT_PULLUP);
  pinMode(ENABLE_PIN_1, OUTPUT);
  pinMode(ENABLE_PIN_2, OUTPUT);
  digitalWrite(ENABLE_PIN_1, HIGH);
  digitalWrite(ENABLE_PIN_2, HIGH);

  loadHistory();
}

void loop() {
  // Handle web server requests
  server.handleClient();

  int buttonState = digitalRead(BUTTON_PIN);

  if (buttonState != lastButtonState) {
    if (buttonState == LOW) {
      int rpmValue = EEPROMReadInt(ADDR_RPM);
      int revsValue = EEPROMReadInt(ADDR_REVS);
      int basketDepthValue = EEPROMReadInt(ADDR_BASKET_DEPTH);
      int speedValue = EEPROMReadInt(ADDR_SPEED);
      int directionValue = EEPROMReadInt(ADDR_DIRECTION);

      // Activate motors
      digitalWrite(ENABLE_PIN_1, LOW);
      digitalWrite(ENABLE_PIN_2, LOW);

      // Wait 0.5 seconds
      delay(500);

      // Lift portafilter
      liftPortafilter(basketDepthValue, speedValue);

      // Spin distributor
      spinDistributor(rpmValue, revsValue, directionValue);

      // Lower portafilter
      lowerPortafilter();

      // Deactivate motors
      digitalWrite(ENABLE_PIN_1, HIGH);
      digitalWrite(ENABLE_PIN_2, HIGH);

      // Add a new history item
      addHistoryItem(rpmValue, revsValue, basketDepthValue, speedValue, directionValue);
    }

    delay(50);
  }

  lastButtonState = buttonState;
}

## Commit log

2024-08-05 BOM and organising files
    [LEAD SCREW MOUNT.stl]
2024-09-20 Added STEP files
    [Assembly 1 - BODY LOWER LEFT.step, Assembly 1 - BODY LOWER RIGHT.step, Assembly 1 - BODY UPPER LEFT.step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]
